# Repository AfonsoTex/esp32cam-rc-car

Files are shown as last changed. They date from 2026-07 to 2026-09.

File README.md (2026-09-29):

# ESP32-CAM RC Car

A remote-controlled car built on the AI-Thinker ESP32-CAM: live video streaming and gamepad control over WiFi, plus an autonomous line-following mode driven by computer vision on the PC.

This repository contains the ESP32-CAM car, its PC server, and the chassis files.
Video, driving commands, discovery, and heartbeats use UDP. TCP is only used
to configure WiFi credentials in Access Point mode.

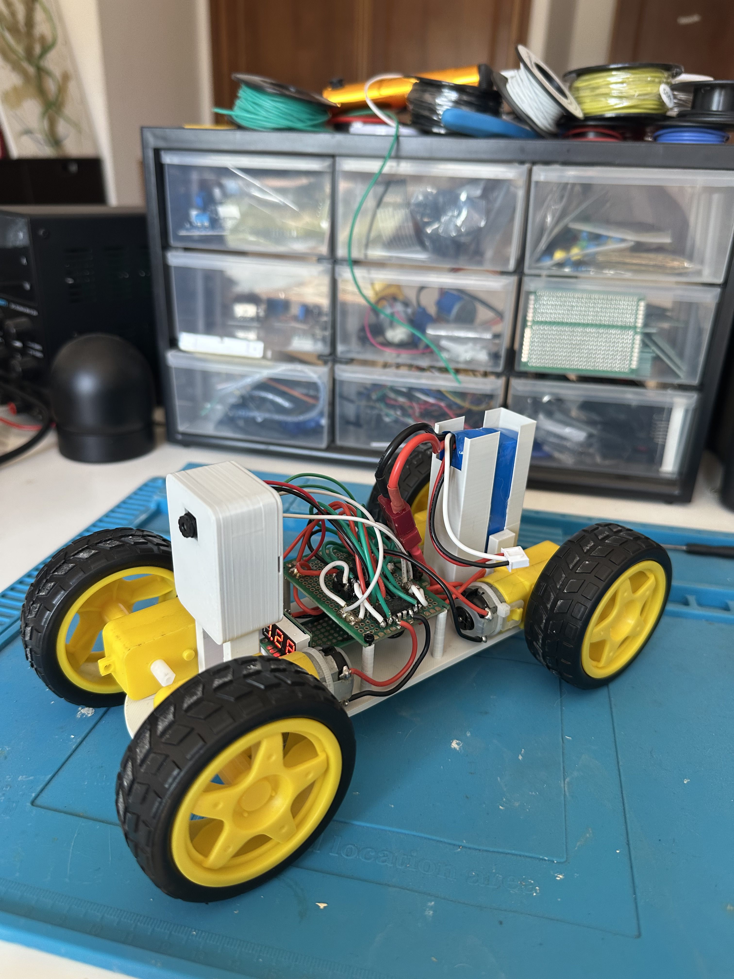
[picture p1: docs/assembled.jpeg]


## What it does

The car has two modes, toggled with the gamepad:

- **Manual** — drive it with an Xbox controller over WiFi.
- **Autonomous line following** — the PC analyses the camera stream, finds a line on the floor, and steers the car along it on its own.

On boot, the ESP32 reads the WiFi networks stored in its flash (NVS) and scans for a saved network it can connect to. If none is available, it falls back to **Access Point mode**: it creates its own network (name set in `config.h`). Connect to that network and use a TCP tool like Packet Sender to send `WIFI:ssid,password` followed by a newline to `192.168.4.1:1883`. After saving the credentials, send `RESET:NOW` followed by a newline to restart.

## Architecture

The ESP32 stays "dumb" on purpose: it captures and sends frames, receives commands, and drives the motors. All the thinking happens on the PC.

**On the ESP32 (two cores, so heavy video never blocks driving):**
- **Core 0** captures JPEG frames from the OV2640 and streams them to the PC over **UDP** (port 1884).
- **Core 1** receives `MOV:x,DIR:y` commands over **UDP** (port 1883) and drives the motors.

**On the PC (`server/unified_python_server - UDP.py`), three threads:**
- **Receive** — reads UDP video packets and reassembles each JPEG frame, keeping only the most recent one.
- **Processing** — runs the vision pipeline (grayscale, threshold, morphology, contours), finds the line's centre, computes steering, and runs the follow/recovery state machine.
- **Main** — reads the gamepad and sends commands to the car.

**Why UDP for video:** with live video you want the *freshest* frame, not a backed-up queue of old ones. TCP resends lost packets and everything waits; UDP drops a lost frame and moves on. A JPEG frame is reassembled from packets using its start/end markers (`FF D8` / `FF D9`).

A heartbeat keeps the link alive: if UDP commands go silent for 1 s the motors stop, and after 5 s the ESP32 sends `HELLO` packets to rediscover the PC. If WiFi is lost for 10 s the chip restarts.

## Line following

The vision pipeline, per frame:
1. **Grayscale** — colour doesn't matter, only dark vs light.
2. **ROI** — crop a strip near the bottom (the floor in front of the car), so walls and furniture don't interfere.
3. **Threshold** — separate the line from the floor (adaptive threshold handles uneven lighting).
4. **Morphology** — clean up noise.
5. **Contours** — find the line, filter out reflections and floor patches by size/shape, pick the right one.
6. **Centre + error** — the line's horizontal centre vs the image centre gives the steering error.
7. **Proportional control** — steering is proportional to the error.

A small **state machine** handles losing the line: normal follow, and a recovery state that reverses to bring the line back into view when it disappears in a sharp curve.

## Hardware

- AI-Thinker ESP32-CAM (ESP32-S + OV2640)
- 2× L293D H-bridges (four DC motors, two per side)
- 3D-printed chassis (see `hardware/`)
- 7.4 V LiPo battery + 5 V regulator

## Build

<div align="center">
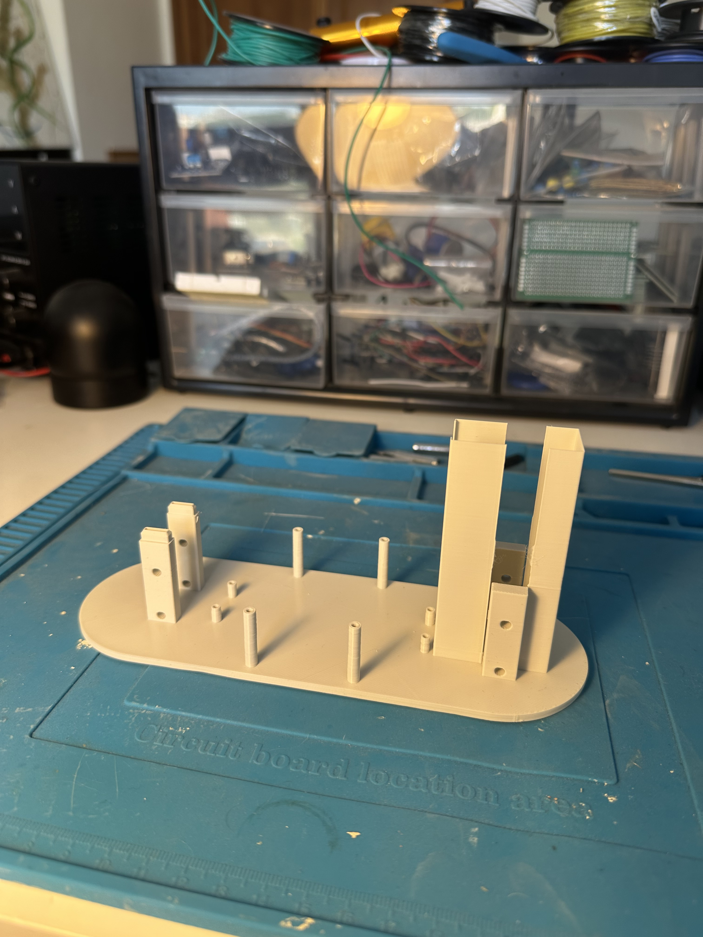
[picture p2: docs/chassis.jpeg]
  <br>
  <em>Printed chassis: battery holder, screw mounts for the protoboards, and mounts for the ESP32-CAM housing.</em>
</div>

<br>

<div align="center">
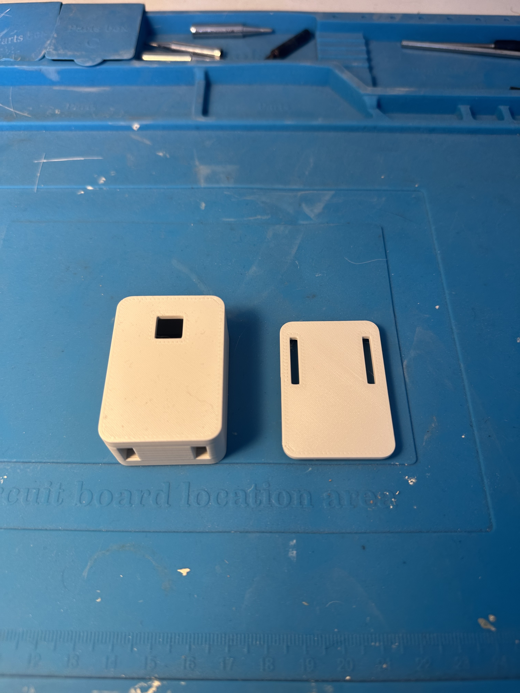
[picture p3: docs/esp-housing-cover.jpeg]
  <br>
  <em>ESP32-CAM housing and cover (front).</em>
</div>

<br>

<div align="center">
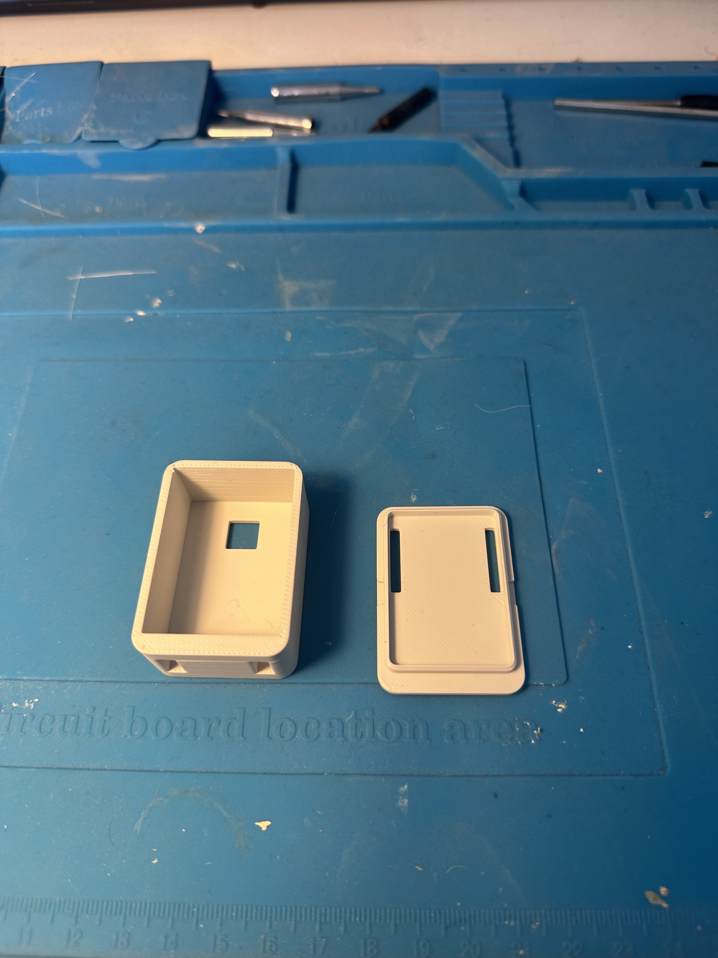
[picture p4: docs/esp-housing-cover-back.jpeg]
  <br>
  <em>Housing and cover (back).</em>
</div>

## Demo

**Manual control**

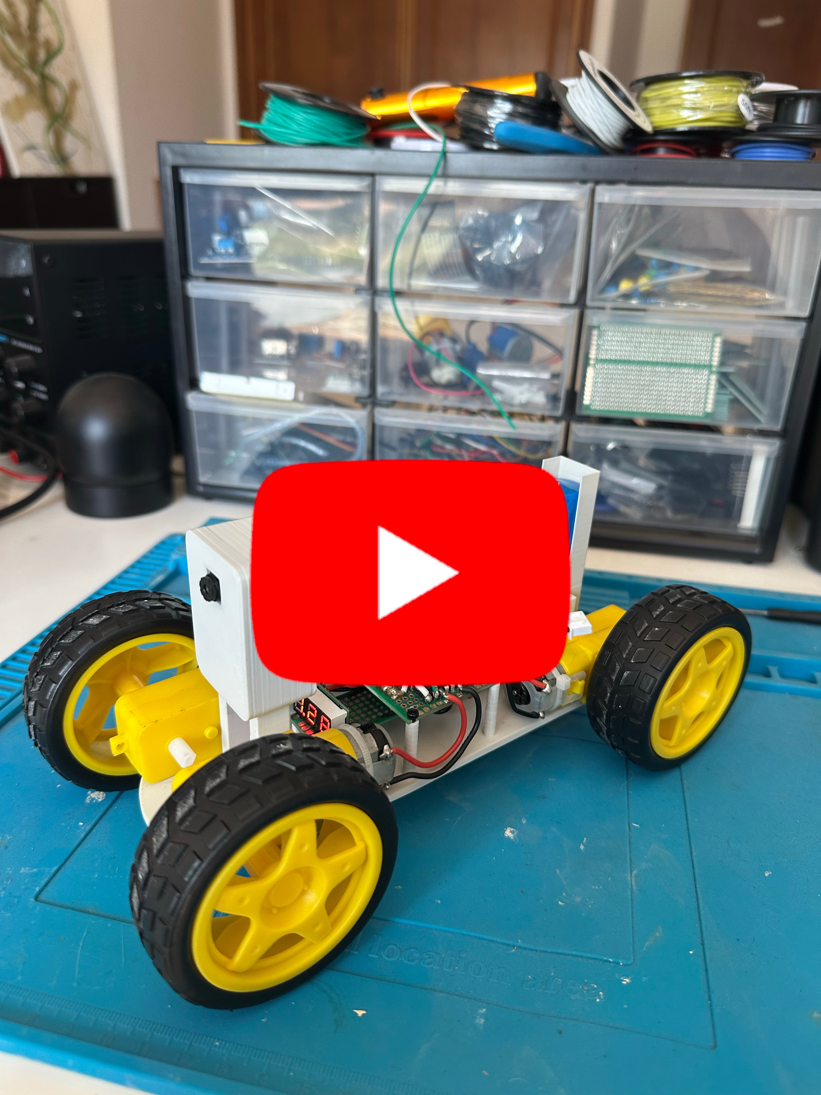
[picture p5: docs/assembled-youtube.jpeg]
<div align="center"></div>

**Autonomous line following**

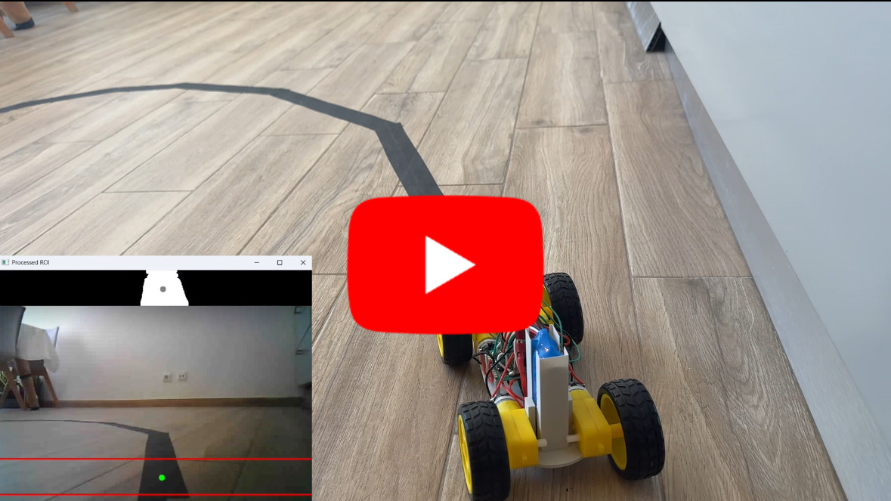
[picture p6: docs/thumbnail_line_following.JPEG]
<div align="center"></div>

## How to use

**Firmware**
1. Install the ESP32 board package in Arduino IDE (Boards Manager → "esp32" by Espressif). Board: **AI Thinker ESP32-CAM**.
2. Open `firmware/main/main.ino`. Edit `config.h` and set your PC IP and AP credentials.
3. Upload to the ESP32.

**PC server**
1. Install the dependencies with `python -m pip install opencv-python numpy pygame`, then run `python "server/unified_python_server - UDP.py"` from the repository root.
2. Power the car. It connects automatically.
3. Press gamepad button 0 (A on the Xbox controller) to toggle between manual and line-following modes.

**Network**
- **Same network (local):** set `DESTINO_IP` in `config.h` to the PC's private IP (`192.168.x.x`). Lowest latency.
- **Over the internet:** forward ports **1883** (UDP) and **1884** (UDP) on the router to the PC, and set `DESTINO_IP` to the router's public IP.
  - Note: if the car and PC are on the *same* network but you use the public IP, many routers won't route it back inside (no NAT loopback). Use the private IP in that case.

## Tuning (important — read this)

The line follower is **not plug-and-play**. The parameters at the top of `server/unified_python_server - UDP.py` must be adjusted to **your** floor, tape, lighting, and car. Key ones:

- **Tape and floor contrast.** The line must stand out from the floor in brightness. Dark tape on a light floor works; matte tape and a non-reflective floor avoid the light-reflection problems that plagued early tests (reflections read as near-white and confuse detection).
- **Threshold / block size.** Adjust so the processed view shows a clean solid line, no floor patches, no holes.
- **GAIN, DEADBAND.** Steering response — raise GAIN if it doesn't turn enough, lower it if it snakes.
- **ROI height.** How far ahead the car looks.

**Battery note:** motor behaviour depends on battery charge. The minimum duty a motor needs to turn is **higher on a low battery** than on a full one — the same value sent to the enable pin does *not* produce the same motion as the battery drains. Speed parameters may need adjusting as the battery discharges.

## Known limitations

- **Turning radius.** The car is differential-drive with shared direction pins (both L293Ds share IN pins), so it can't pivot in place. Sharp curves can exceed its turning ability; the recovery state (reversing) helps but doesn't fully solve very tight turns.
- **WiFi range.** The ESP32-CAM's on-board antenna is weak. Far from the router the link degrades. An external antenna (via the u.FL connector, if present) helps a lot.
- **Power.** Camera + WiFi draw current spikes; an undersized regulator can brown out and reset the chip. A large capacitor across the 5 V input helps.

## Repository layout

```
firmware/main/   ESP32 firmware (main.ino) + config.h
server/          unified_python_server - UDP.py (video + control + line following)
hardware/        3D chassis (STL to print, F3D source)
docs/            photos, thumbnails
```

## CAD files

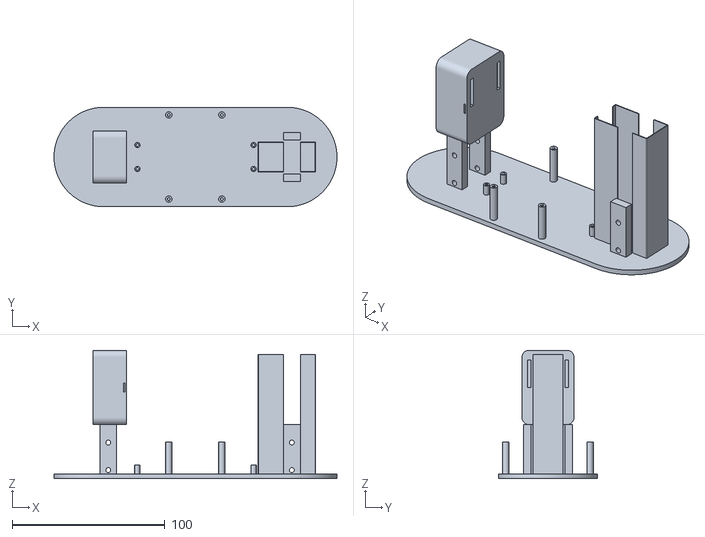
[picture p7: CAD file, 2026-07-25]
hardware/Chassis.stl
185.0 x 65.0 x 83.9

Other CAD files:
hardware/Chassis.f3d

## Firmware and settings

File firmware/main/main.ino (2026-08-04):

#include "config.h"
#include <WiFiUdp.h>
#include <stdio.h>        // printf / sprintf
#include "nvs_flash.h"    // NVS partition init (non-volatile storage in flash)
#include "nvs.h"          // NVS read/write API for WiFi credentials
#include <WiFi.h>         // STA/AP mode, network scan, TCP sockets
#include "esp_camera.h"   // OV2640 driver and JPEG frame capture

// ── OV2640 camera pin map (AI-Thinker ESP32-CAM)
// The ESP32-CAM board carries the ESP32-S module and the OV2640 sensor
// wired together on the same PCB.
// These pin numbers describe how the OV2640 sensor is physically wired
// to the ESP32 on this board. The wiring is fixed in the PCB and cannot
// be changed. The camera driver cannot detect it, so it must be told.
// Wrong number here = driver talks to the wrong pin = camera never responds.
// Source: ESP32_CAM_V1.6 schematic (docs/ESP32_CAM_V1_6.pdf).
#define PWDN_GPIO_NUM     32
#define RESET_GPIO_NUM    -1
#define XCLK_GPIO_NUM      0
#define SIOD_GPIO_NUM     26
#define SIOC_GPIO_NUM     27

#define Y9_GPIO_NUM       35
#define Y8_GPIO_NUM       34
#define Y7_GPIO_NUM       39
#define Y6_GPIO_NUM       36
#define Y5_GPIO_NUM       21
#define Y4_GPIO_NUM       19
#define Y3_GPIO_NUM       18
#define Y2_GPIO_NUM        5

#define VSYNC_GPIO_NUM    25
#define HREF_GPIO_NUM     23
#define PCLK_GPIO_NUM     22


// Layout version of the credentials record saved in NVS. Bump by hand
// when the struct fields below change, so old records can be told apart.
// (Written on save; not yet checked on read.)
#define WIFI_STORAGE_VERSION 1

typedef struct {
    uint8_t version;
    char ssid[32];
    char password[64];
} my_wifi_credentials_t;


// Debug only: prints every WiFi network stored in flash.
void dump_nvs_to_serial() {
    nvs_handle_t h;
    uint32_t count = 0;

    if (nvs_open("wifi_storage_id", NVS_READONLY, &h) != ESP_OK) {
        Serial.println("[NVS] Namespace empty or not found");
        return;
    }
    nvs_get_u32(h, "wifi_count", &count);
    Serial.printf("[NVS] Total networks: %lu\n", count);

    for (uint32_t i = 0; i < count; i++) {
        char key[16];
        sprintf(key, "wifi_%lu", i);
        my_wifi_credentials_t net;
        size_t size = sizeof(my_wifi_credentials_t);
        if (nvs_get_blob(h, key, &net, &size) == ESP_OK) {
            Serial.printf("[NVS] [%lu] SSID: %s | PASS: %s\n", i, net.ssid, net.password);
        }
    }
    nvs_close(h);
}

// Fixed size buffer: String/malloc would fragment the heap over thousands of
// iterations, and the camera needs large contiguous blocks per JPEG frame.
char buffer[128];

// IP of the PC running the Python servers. The ESP32 is the client:
// on boot it connects out to this address, so it must know it up front.
// Set this in config.h — it changes with your network.
const char *destino = DESTINO_IP;

// Port where comandos.py listens. Video uses 1884 (see camara.py).
// IP picks the machine, port picks which program on it.
#define SERVER_PORT 1883
#define VIDEO_PORT 1884

// Last time any data arrived from the PC. Silence for >1 s stops the
// motors; >5 s drops the TCP connection.
unsigned long lastHeartbeat = 0;
unsigned long wifiLostTimestamp = 0;
bool trackingLostWifi = false;
unsigned long lastReconnectAttempt = 0;

// TCP server, used ONLY in Access Point mode (initial WiFi setup).
// With no known network, the ESP32 becomes the AP "ESP32_CAM_AFONSO".
// You connect to it and send "WIFI:ssid,password\n" to this port to
// store a new network in NVS flash.
WiFiServer ESPserver(1883);

// Normal mode: the ESP32 is the client on both connections.
WiFiClient client;         // commands from comandos.py, port 1883
//WiFiClient clienteVideo;   // JPEG frames to camara.py, port 1884

// Declares the UDP object responsible for managing the video streaming channel
WiFiUDP udpVideo;

// clock frequency, pixel format, frame size, number of frame buffers.
// Declared empty here, filled field by field in setup(), then handed to
// esp_camera_init(&config).
camera_config_t config;

// ── H-bridge (L293D) ──────────────────────────────────────────────
// EN pins carry PWM and set how much power each side gets.
// IN pins are digital only and set the direction, shared by both motors:
// both go forward or both go backward, never one each way.
// Steering comes from feeding the two sides different PWM duty.
const int EN1_pin = 14;   // PWM, left side
const int EN2_pin = 15;   // PWM, right side
const int IN1_pin = 12;   // direction pair: HIGH/LOW = forward
const int IN2_pin = 13;   //                 LOW/HIGH = backward

// LEDC hardware channels for the two PWM outputs.
const int PWM_CHANNEL_1 = 0;
const int PWM_CHANNEL_2 = 1;

void stop_motors() {
    ledcWrite(EN1_pin, 0);
    ledcWrite(EN2_pin, 0);
}

void pinos_setup() {
    pinMode(IN1_pin, OUTPUT);
    pinMode(IN2_pin, OUTPUT);

    digitalWrite(IN1_pin, LOW);
    digitalWrite(IN2_pin, LOW);
}

void pwm_channel_setup() {
    // ledcAttachChannel also sets the pin as output, so no pinMode needed.
    ledcAttachChannel(EN1_pin, 1000, 8, PWM_CHANNEL_1);
    ledcAttachChannel(EN2_pin, 1000, 8, PWM_CHANNEL_2);
}

void setup_flash_memory() {
    esp_err_t return_error_value = nvs_flash_init();
    if (return_error_value == ESP_ERR_NVS_NO_FREE_PAGES || return_error_value == ESP_ERR_NVS_NEW_VERSION_FOUND) {
        nvs_flash_erase();
        nvs_flash_init();
    }
}

// Credentials of the config network the ESP32 creates when it has no
// known WiFi. Set in config.h.
const char *ap_ssid     = AP_SSID;
const char *ap_password = AP_PASSWORD;

void enable_access_point() {
    WiFi.mode(WIFI_AP);
    WiFi.softAP(ap_ssid, ap_password);
    Serial.println("\n--- ACCESS POINT MODE ---");
    Serial.print("IP: "); Serial.println(WiFi.softAPIP());
    ESPserver.begin();
}


// Stores one WiFi network in NVS flash. Called from AP mode with the
// ssid and password parsed from the WIFI: command.
// Fills the struct, reads the current count, saves the record under key
// "wifi_<count>", then increments the count. Numbered keys let several
// networks be stored and read back later by dump / the scan on boot.
void Write_to_flash(char *ssid, char *password) {
    nvs_handle_t my_handle;
    my_wifi_credentials_t my_network;
    uint32_t count;

    memset(&my_network, 0, sizeof(my_wifi_credentials_t));
    my_network.version = WIFI_STORAGE_VERSION;

    strncpy(my_network.ssid, ssid, sizeof(my_network.ssid) - 1);
    strncpy(my_network.password, password, sizeof(my_network.password) - 1);

    esp_err_t err = nvs_open("wifi_storage_id", NVS_READWRITE, &my_handle);
    if (err != ESP_OK) {
        Serial.println("Error opening NVS handle!");
        return;
    }

    err = nvs_get_u32(my_handle, "wifi_count", &count);
    if (err == ESP_ERR_NVS_NOT_FOUND) {
        count = 0;
        nvs_set_u32(my_handle, "wifi_count", count);
    }

    char key[16];
    sprintf(key, "wifi_%lu", count);

    err = nvs_set_blob(my_handle, key, &my_network, sizeof(my_wifi_credentials_t));
    if (err == ESP_OK) {
        count++;
        nvs_set_u32(my_handle, "wifi_count", count);
        nvs_commit(my_handle);
    } else {
        Serial.printf("Error writing blob: %s\n", esp_err_to_name(err));
    }
    dump_nvs_to_serial();
    nvs_close(my_handle);
}


// Loop that runs in AP mode. Reads and handles the commands you send
// from Packet Sender. Infinite: only the ESP.restart() below leaves it.
// WIFI:ssid,password -> Write_to_flash() stores the network
// RESET:NOW          -> reboots the chip
void loop_config_mode() {
    Serial.println("Entering infinite config loop...");

    while (true) {
        WiFiClient configClient = ESPserver.available();

        if (configClient) {
            Serial.println("Config client detected.");

            while (configClient.connected() || configClient.available() > 0) {
                if (configClient.available() > 0) {
                    memset(buffer, 0, sizeof(buffer));
                    int n = configClient.readBytesUntil('\n', buffer, sizeof(buffer) - 1);

                    if (n > 0) {
                        buffer[n] = '\0';
                        if (buffer[n - 1] == '\r') buffer[n - 1] = '\0';

                        if (strncmp(buffer, "WIFI:", 5) == 0) {
                            char *ssid = buffer + 5;
                            char *virgula = strchr(ssid, ',');
                            if (virgula != NULL) {
                                *virgula = '\0';
                                char *password = virgula + 1;
                                Write_to_flash(ssid, password);
                                configClient.println("OK: Network saved.");
                            }
                        } else if (strncmp(buffer, "RESET:NOW", 9) == 0) {
                            configClient.println("OK: Restarting...");
                            delay(500);
                            ESP.restart();
                        }
                    }
                }
            }
            Serial.println("Client disconnected. Waiting...");
        }
        delay(10);
    }
}


// Turns speed and steering (both -1..1, from the PC) into direction and
// per-side power. IN pins set direction for both motors; the EN duty of
// each side is cut by the steering amount
void motor_logic(float speed, float steering) {
    Serial.printf("MOTOR: speed=%.2f steering=%.2f\n", speed, steering);

    // Direction
    if(speed == 0){
        digitalWrite(IN1_pin, LOW);
        digitalWrite(IN2_pin, LOW);
    }
    else if(speed > 0){
        digitalWrite(IN1_pin, HIGH);
        digitalWrite(IN2_pin, LOW);
    }
    else if(speed < 0){
        digitalWrite(IN1_pin, LOW);
        digitalWrite(IN2_pin, HIGH);
    }

    // Velocity
    int en_esquerda = 0;
    int en_direita = 0;

    if(steering >= 0){
        en_esquerda = (int)(speed * 255);
        en_direita  = (int)(speed * 255 * (1 - steering));
    }
    else{
        en_direita  = (int)(speed * 255);
        en_esquerda = (int)(speed * 255 * (1 + steering));
    }

    ledcWrite(EN1_pin, abs(en_esquerda));
    ledcWrite(EN2_pin, abs(en_direita));
    Serial.printf("EN_LEFT=%d EN_RIGHT=%d\n", abs(en_esquerda), abs(en_direita));
}

/*void task_camara(void *parameter) {
    Serial.printf("Camera task running on Core %d\n", xPortGetCoreID());

    while (true) {
        if (!clienteVideo.connected()) {
            Serial.println("[VIDEO] Trying to connect to PC...");
            if (clienteVideo.connect(destino, VIDEO_PORT)) {
                Serial.println("[VIDEO] Connected!");
            } else {
                Serial.println("[VIDEO] Connection failed");
                vTaskDelay(2000 / portTICK_PERIOD_MS);
                continue;
            }
        }

        camera_fb_t *fb = esp_camera_fb_get();
        if (fb == NULL) {
            Serial.println("[VIDEO] Frame capture failed");
            vTaskDelay(100 / portTICK_PERIOD_MS);
            continue;
        }

        uint32_t tamanho = fb->len;
        clienteVideo.write((uint8_t*)&tamanho, 4);
        clienteVideo.write(fb->buf, fb->len);

        esp_camera_fb_return(fb);

        vTaskDelay(1 / portTICK_PERIOD_MS);
    }
}
*/

void task_camara(void *parameter) {
    // Initializes the UDP socket on the specified port to start sending camera frames
    udpVideo.begin(VIDEO_PORT);

    while (true) {
        // GOLDEN RULE: Only stream video if the control TCP connection is active.
        // This prevents UDP from flooding the network and blocking the TCP handshake.
        if (!client.connected()) {
            vTaskDelay(100 / portTICK_PERIOD_MS);
            continue;
        }

        // Capture a frame from the OV2640 camera sensor
        camera_fb_t *fb = esp_camera_fb_get();
    
        // Check if the frame was successfully captured
        if (fb != NULL) {
            // Begin building a UDP packet targeted at the destination IP and video port
            udpVideo.beginPacket(destino, VIDEO_PORT);
            
            // Write the raw JPEG buffer data into the UDP packet stream
            udpVideo.write(fb->buf, fb->len);
            
            // Send the completed UDP packet across the network
            udpVideo.endPacket();
            
            // Return the frame buffer to the driver pool so memory can be reused
            esp_camera_fb_return(fb);
        }
        
        // Delay task execution to maintain a target rate of approximately 30 frames per second
        vTaskDelay(33 / portTICK_PERIOD_MS); 
    }
}

void processar_comando(char* data) {
    Serial.print("Command received to process: ");
    Serial.println(data);

    // Parses a "MOV:x,DIR:y" line and drives the motors with x and y.
    // data+4 skips "MOV:"; strchr finds the comma; writing '\0' over the
    // comma splits the string so mov holds only x. virgula+5 skips ",DIR:".
    // atof turns each number text into a float.

    char *mov = data + 4;
    char *virgula = strchr(mov, ',');

    float move = 0.0;
    float direc = 0.0;

    if (virgula != NULL) {
        *virgula = '\0';
        char *dir_str = virgula + 5;   // assumes fixed ",DIR:" prefix

        move  = atof(mov);
        direc = atof(dir_str);
        motor_logic(move, direc);
    }
}

void setup() {
    Serial.begin(115200);
    pinos_setup();          // motor direction pins
    pwm_channel_setup();    // motor PWM on LEDC channels 0/1
    setup_flash_memory();   // init NVS partition
    dump_nvs_to_serial();   // debug: print stored networks

    // ── Camera configuration: fill the config struct field by field ───
    // Pin map (source: ESP32_CAM_V1.6 schematic, docs/ESP32_CAM_V1_6.pdf)
    config.pin_pwdn     = PWDN_GPIO_NUM;
    config.pin_reset    = RESET_GPIO_NUM;
    config.pin_xclk     = XCLK_GPIO_NUM;
    config.pin_sccb_sda = SIOD_GPIO_NUM;
    config.pin_sccb_scl = SIOC_GPIO_NUM;
    config.pin_d7 = Y9_GPIO_NUM;
    config.pin_d6 = Y8_GPIO_NUM;
    config.pin_d5 = Y7_GPIO_NUM;
    config.pin_d4 = Y6_GPIO_NUM;
    config.pin_d3 = Y5_GPIO_NUM;
    config.pin_d2 = Y4_GPIO_NUM;
    config.pin_d1 = Y3_GPIO_NUM;
    config.pin_d0 = Y2_GPIO_NUM;
    config.pin_vsync = VSYNC_GPIO_NUM;
    config.pin_href  = HREF_GPIO_NUM;
    config.pin_pclk  = PCLK_GPIO_NUM;

    config.xclk_freq_hz = 20000000;      // 20 MHz clock the ESP32 generates and
                                         // feeds to the sensor (it has no
                                         // oscillator of its own). 20 MHz is the
                                         // OV2640 datasheet recommended value.
    config.ledc_timer   = LEDC_TIMER_1;  // LEDC timer+channel used to produce that
    config.ledc_channel = LEDC_CHANNEL_2;// XCLK. Channel 2, so it does not clash
                                         // with channels 0/1 driving the motors.
    config.pixel_format = PIXFORMAT_JPEG; // sensor outputs JPEG, already compressed
    config.frame_size = FRAMESIZE_VGA;
    config.jpeg_quality = 30;           // 0=best/largest, 63=worst; higher = smaller frame
    config.fb_count     = 2;              // two frame buffers: capture one while sending the other
    config.fb_location  = CAMERA_FB_IN_PSRAM; // frames go in PSRAM; too big for internal RAM
    config.grab_mode    = CAMERA_GRAB_WHEN_EMPTY; // fetch a new frame only when a buffer is free

    esp_err_t err_cam = esp_camera_init(&config);
    if (err_cam != ESP_OK) {
        Serial.printf("Camera init failed: 0x%x\n", err_cam);
    } else {
        Serial.println("Camera OK");
    }

    // ── WiFi: try saved networks, or fall back to AP mode ─────────────
    nvs_handle_t my_handle_read;
    uint32_t count = 0;
    esp_err_t err = nvs_open("wifi_storage_id", NVS_READONLY, &my_handle_read);

    // No stored networks: either the namespace was never created (no network
    // ever saved) or the wifi_count key is missing. Both mean zero networks,
    // so fall into AP mode and stay in the config loop until you send one.
    // enable_access_point(): ESP32 creates its own network (ESP32_CAM_AFONSO),
    //   takes IP 192.168.4.1, opens the TCP server on port 1883.
    // loop_config_mode(): infinite loop reading your commands, saves the
    //   network you send to flash. Never returns — only leaves on chip reset
    //   (the RESET:NOW you send from Packet Sender).
    if (err != ESP_OK || nvs_get_u32(my_handle_read, "wifi_count", &count) != ESP_OK) {
        nvs_close(my_handle_read);
        enable_access_point();
        loop_config_mode();
    } else {
        int numero_redes_ar = WiFi.scanNetworks();
        bool conectou = false;
        my_wifi_credentials_t net;                    // buffer for each network read from flash
        size_t size = sizeof(my_wifi_credentials_t);

        // Match saved networks against what's on the air.
        // Outer loop: networks currently in range (i). Inner loop: networks
        // saved in flash (j, count of them). For each network in range, look
        // for a saved one with the same SSID; on a match, try to connect.
        for (int i = 0; i < numero_redes_ar && !conectou; i++) {
            for (uint32_t j = 0; j < count; j++) {

                // Build the NVS key for saved network j: "wifi_0", "wifi_1", ...
                char key[16];
                sprintf(key, "wifi_%lu", j);

                // match found: this saved network is in range. try to connect.
                if (nvs_get_blob(my_handle_read, key, &net, &size) == ESP_OK
                    && strcmp(net.ssid, WiFi.SSID(i).c_str()) == 0) {

                    Serial.printf("Trying: %s\n", net.ssid);
                    WiFi.begin(net.ssid, net.password);

                    // wait up to 10 s for the connection
                    unsigned long t0 = millis();
                    while (WiFi.status() != WL_CONNECTED && millis() - t0 < 10000) {
                        delay(500);
                        Serial.print(".");
                    }

                    if (WiFi.status() == WL_CONNECTED) {
                        Serial.printf("\nConnected to: %s\n", net.ssid);
                        conectou = true;
                    } else {
                        Serial.printf("\nFailed: %s\n", net.ssid);
                        WiFi.disconnect();
                        delay(200);
                    }
                    break;   // SSID matched; stop scanning flash for this network
                }
            }
        }

        nvs_close(my_handle_read);

        // none of the saved networks was in range or accepted the connection:
        // fall back to AP mode, same as the no-networks case above.
        if (!conectou) {
            Serial.println("All networks failed. Fallback mode.");
            enable_access_point();
            loop_config_mode();
        }

        // WiFi is up: launch the camera streaming task pinned to Core 0,
        // so heavy JPEG sending never blocks the motor commands on Core 1.
        xTaskCreatePinnedToCore(
            task_camara,    // function the task runs
            "task_camara",  // name, debug only
            10000,          // stack size in bytes
            NULL,           // no argument
            1,              // priority
            NULL,           // task handle not kept
            0               // Core 0
        );
    }
}



void loop() {
    // Layer 1 — is WiFi connected?
    // If not: stop the motors and start timing the outage (trackingLostWifi
    // makes sure the instant is recorded only once). After 10 s down,
    // ESP.restart(). The return blocks everything else — no WiFi, nothing to
    // do. If connected, clear the flag so the next outage is timed fresh.
    if (WiFi.status() != WL_CONNECTED) {
        stop_motors();
        if (!trackingLostWifi) {
            wifiLostTimestamp = millis();
            trackingLostWifi = true;
        }
        if (millis() - wifiLostTimestamp > 10000) ESP.restart();
        return;
    }
    trackingLostWifi = false;

    // Layer 2 — is the TCP link to the PC up?
    // If down: stop the motors and retry connect once every 5 s (connect
    // blocks while waiting, so calling it every loop would trap us here).
    // Reset lastHeartbeat either way so the fresh link isn't seen as silent.
    if (!client.connected()) {
        stop_motors();
        if (millis() - lastReconnectAttempt > 5000) {
            lastReconnectAttempt = millis();
            Serial.printf("[%lu] Trying to reach the PC...\n", millis());
            if (client.connect(destino, SERVER_PORT)) {
                Serial.printf("[%lu] Connected successfully!\n", millis());
                lastHeartbeat = millis();
            } else {
                lastHeartbeat = millis();
                Serial.printf("[%lu] CONNECTION FAILED!\n", millis());
            }
        }
        return;
    }

    // Layer 3 — silence watchdog. PC sends HB every 0.2 s, so silence = trouble.
    if (millis() - lastHeartbeat > 1000) {
        stop_motors();                    // 1 s: safety stop
    }

    if (millis() - lastHeartbeat > 5000) {
        Serial.printf("[%lu] HEARTBEAT TIMEOUT - closing!\n", millis());
        client.stop();                    // 5 s: assume dead, drop the socket
        lastReconnectAttempt = millis();
    }

    // Layer 4 — read all pending lines; only MOV: lines drive the motors.
    if (client.available() > 0) {
        while (client.available() > 0) {
            memset(buffer, 0, sizeof(buffer));
            client.readBytesUntil('\n', buffer, sizeof(buffer) - 1);
            lastHeartbeat = millis();
        }

        if (strncmp(buffer, "MOV:", 4) == 0) {
            processar_comando(buffer);
        }
    }
}

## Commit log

2026-07-25 Add chassis 3D files (STL for printing, F3D source)
    [Chassis.f3d, Chassis.stl]
2026-07-27 Rename assembled youtube.jpeg to assembled-youtube.jpeg
2026-08-04 Refactor unified server, UDP and auto-mode
    Merge camera and control scripts into a single server, migrate to UDP protocol, add a 3-thread architecture, and implement autonomous line-following mode.
2026-08-04 docs: add ESP32-CAM and OV2640 datasheets and technical manuals
2026-08-04 refactor: switch video stream to UDP protocol
